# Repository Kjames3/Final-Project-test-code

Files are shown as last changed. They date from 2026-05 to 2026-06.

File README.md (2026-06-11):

# Jumping Wheel-Legged Robot — EE 244 Final Project

This repository contains the software verification, hardware calibration, and operational scripts for our double-wheel parallel four-bar linkage jumping robot.

---

## 👥 Team Members
* **Kamren James**
* **Shashwat Hitesh Shah**
* **Bhargav Srikanta Prasad Hoskote**
* **Jaya Surya Varma Pelluri**

---

## Project Objective & Inspiration
Our goal is to design, construct, and program a double-wheeled parallel-linkage robot that can stably balance on flat terrain and dynamically contract/expand its legs to jump over obstacles.

We aim to **emulate the physical results and dynamic control systems** described in the research paper:
> **"Design and dynamic analysis of jumping wheel-legged robot in complex terrain environment"**
> *Frontiers in Neurorobotics (2022) | DOI: 10.3389/fnbot.2022.1066714*
> *(Accessible at: [Documents/fnbot-16-1066714 (1).pdf](file:///home/kamren/Final-Project-test-code/Documents/fnbot-16-1066714%20(1).pdf))*

### Constraints & Scope
* **Budget Limit:** **$120** (strictly enforced for structure, motors, drivers, and microcontrollers)
* **Core Goal:** Build a working prototype leveraging parallel four-bar linkages, implementing a LQR self-balancing controller (on wheel motors) and dynamic height-changing/jumping mechanics (via hip serial bus servos).

---

## Hardware Specification Summary

Detailed wiring, schematic connections, and Pinout maps are maintained in [Assembly.md](file:///home/kamren/Final-Project-test-code/Assembly.md).

* **Hips (Leg Linkages):** 2x BLS3355 61kg brushless RC servos (PWM, driven from Arduino D3/D11). *Replaced the original Feetech STS3215 serial-bus servos after a burned H-bridge — see [BillOfMaterials.md](file:///home/kamren/Final-Project-test-code/BillOfMaterials.md).*
* **Wheels:** 2x JGB-520 12V 550 RPM DC Motors with Hall-effect encoders
* **Microcontroller:** Arduino Uno R3 (200 Hz LQR balance loop, encoders, IMU, motor + hip PWM)
* **Controller:** Raspberry Pi (running Pi OS Lite / Bookworm)
* **Network Status Display:** 1.3" IIC V2.2 OLED (SH1106 driver, 128x64px)

---

## Scripts & Codebase Guide

The simplest entry point is the unified hub — `python3 robot_control.py` — which auto-detects the Arduino port and launches every test below from a menu. The individual scripts can also be run directly.

### `robot_control.py` (hub)
The central ANSI-styled console: scans serial ports, shows connection health, and launches wheel tests, the IMU monitor, hip stance, the remote-control server, the web tuning dashboard, BLS servo diagnostics, live telemetry, and pitch-offset calibration.

### `display_ip.py`
A daemon that drives the 1.3" I2C OLED screen, showing the active Wi-Fi SSID, `wlan0` IP, and hostname so the team can SSH in on boot without an HDMI monitor.
* **How to run manually:** `python3 scripts/display_ip.py`
* **Automated start:** Installed as a systemd service (`oled-display.service`).

### `default_stance.py`
Sends `SRV:` pulse-width commands to the Arduino to drive the two BLS3355 hip servos to the configured default standing stance (`bls.left/right default_us` in `config/robot.yaml`).
* **How to run:** `python3 scripts/default_stance.py`

### `bls_servo_diag.py`
Interactive diagnostic for the BLS3355 PWM hip servos: select left/right/both, center, jog by ±20 μs (~2.7°), absolute pulse, or slow sweep — useful for finding and calibrating the neutral/stance pulse widths.

### `test_wheels.py`
Spins the JGB-520 wheel motors forward/backward and streams live encoder speed + tilt telemetry to verify drive wiring and encoder direction.

### `calibrate_balance_offset.py`
Averages live IMU pitch while you hold the robot at its true balance point, then writes the result to `config/lqr_gains.json` as `balance_offset`.

---

## Quick Setup & Installation

### A. Setup Python Dependencies
On the Raspberry Pi, install all necessary system packages and libraries:
```bash
sudo apt-get update
sudo apt-get install -y python3-pip python3-pil fonts-dejavu-core i2c-tools

# Install project Python deps + the Luma OLED package
pip3 install luma.oled --break-system-packages
pip3 install -r requirements.txt --break-system-packages
```

### B. Auto-Start the OLED Service
To ensure the Pi always shows its IP address when it boots up:
1. Ensure the systemd service file is configured (check paths and username inside [oled-display.service](file:///home/kamren/Final-Project-test-code/oled-display.service)).
2. Install and enable the service:
   ```bash
   sudo cp oled-display.service /etc/systemd/system/
   sudo systemctl daemon-reload
   sudo systemctl enable oled-display
   sudo systemctl start oled-display
   ```
3. Verify it is running properly:
   ```bash
   sudo systemctl status oled-display
   ```

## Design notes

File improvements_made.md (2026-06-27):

# Jumping Wheel-Legged Robot — Log of Improvements Made

This file maintains a chronological log of all code optimizations, bug fixes, and feature enhancements applied to the robot's control system.

---

### [2026-06-14 19:40:00 -07:00] LQR Auto-Tuning Optimization Suite
Implemented key improvements to the Bayesian optimization and telemetry loop to make the auto-tuning process far more precise, consistent, and resistant to hardware calibration offsets.

#### 1. Offset-Independent Variance Cost Function
* **File modified**: [tuning_dashboard.py](file:///home/kamren/Final-Project-test-code/scripts/tuning_dashboard.py)
* **Description**: Replaced the absolute quadratic cost function with a variance-based cost function (measuring deviation from the mean tilt angle and mean wheel speed). This prevents static tilt calibration offsets (e.g. if the robot stands at a slight lean) from dominating the cost metric, isolating and evaluating purely dynamic balance recovery performance.

#### 2. Uniform 1D Grid Search in Bayesian Optimizer
* **File modified**: [bayes_opt.py](file:///home/kamren/Final-Project-test-code/src/utils/bayes_opt.py)
* **Description**: Added a 1D grid search path inside the GP optimizer's parameter candidate generation when `len(self.keys) == 1`. This prevents the optimizer from falling back to random coordinate sampling when tuning a single parameter (such as $K_s$), ensuring it systematically sweeps the bounds to locate the absolute minimum of the acquisition function.

#### 3. Arduino-Coordinated Impulse Taps (Hardware-Timed Disturbances)
* **Files modified**: [robot_control.ino](file:///home/kamren/Final-Project-test-code/robot_control/robot_control.ino), [arduino_bridge.py](file:///home/kamren/Final-Project-test-code/src/drivers/arduino_bridge.py), [tuning_dashboard.py](file:///home/kamren/Final-Project-test-code/scripts/tuning_dashboard.py)
* **Description**: Introduced a custom timed impulse command `IMP:<speed>:<duration_ms>` sent from Python to the Arduino. This offloads the tap duration timing from the Pi's OS to the Arduino's 200 Hz firmware loop, eliminating 10–30 ms of jitter caused by USB latency and thread scheduling to guarantee identical testing impulses across all iterations.

#### 4. Session-Based Auto-Tuning Run Isolation
* **File modified**: [tuning_dashboard.py](file:///home/kamren/Final-Project-test-code/scripts/tuning_dashboard.py)
* **Description**: Modified the auto-tune trial logger to save output files in timestamped session subfolders (`config/autotune_logs/run_YYYYMMDD_HHMMSS/`) to prevent subsequent auto-tuning sweeps from overwriting previous trial logs.

---

### [2026-06-15 00:35:00 -07:00] Real-Time Firmware & Control Optimization Suite (Phase 2)
Implemented firmware-level enhancements in the Arduino real-time controller to improve loop safety, stiction response, sensor fusion, and stopping trajectories.

#### 1. Non-Blocking C-String Command Parser
* **File modified**: [robot_control.ino](file:///home/kamren/Final-Project-test-code/robot_control/robot_control.ino)
* **Description**: Replaced blocking `String`-based serial reading with a non-blocking char buffer accumulator and zero-allocation C library routines (`strncmp`, `sscanf`), guaranteeing the 200 Hz control loop never suffers communication latency spikes.

#### 2. Motor Deadband Compensation
* **File modified**: [robot_control.ino](file:///home/kamren/Final-Project-test-code/robot_control/robot_control.ino)
* **Description**: Added a deadband compensation mapping that shifts LQR output commands past the mechanical stiction threshold (minimum PWM of 25), removing low-amplitude wobbling.

#### 3. Startup Gyro Bias Calibration
* **File modified**: [robot_control.ino](file:///home/kamren/Final-Project-test-code/robot_control/robot_control.ino)
* **Description**: Programmed an automatic zero-rate offset calibration cycle at boot (averaging 400 readings over 1.2s), preventing steady-state complementary filter drift.

#### 4. LQR Integrator Anti-Windup Decay
* **File modified**: [robot_control.ino](file:///home/kamren/Final-Project-test-code/robot_control/robot_control.ino)
* **Description**: Introduced an exponential decay (5% per loop step) on the velocity error accumulator (`posErr`) during active travel commands. This stops integrator windup when moving, resulting in crisp stopping behavior and zero braking drift.

#### 5. Axle Linear Acceleration Compensation
* **File modified**: [robot_control.ino](file:///home/kamren/Final-Project-test-code/robot_control/robot_control.ino)
* **Description**: Multiplied the speed derivative by $1/g$ and subtracted the horizontal axle linear acceleration component from the accelerometer X reading. This prevents the estimated pitch angle from being distorted when the robot accelerates or decelerates.

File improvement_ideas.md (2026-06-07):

# JUMPING WHEEL-LEGGED ROBOT — Codebase & LQR Performance Improvement Ideas

This document maintains a list of recommended optimizations, performance enhancements, and bug fixes identified across the Arduino real-time controller, Pi communication bridge, and the web-based tuning dashboard.

---

## 1. Arduino Uno R3 Control Loop (`robot_control.ino`)

### [OPTIMIZATION] Pre-Calculate Speed Measurement Multipliers
* **Location:** `updateSpeed()` in `robot_control.ino`
* **Current Implementation:**
  ```cpp
  speedL = ((float)dL / ENC_PPR) * WHEEL_CIRC / dt;
  speedR = ((float)dR / ENC_PPR) * WHEEL_CIRC / dt;
  ```
* **Issue:** This performs two floating-point divisions by `ENC_PPR` (660) and two floating-point divisions by `dt` every iteration. Since the Arduino Uno has no hardware FPU, division operations are extremely slow software-emulated routines.
* **Solution:** Since the loop rate is regulated at 200 Hz (`LOOP_HZ = 200`), the time step `dt` is almost always exactly `0.005` seconds. We can precompute the constant multiplier:
  $$\text{Multiplier} = \frac{\text{WHEEL\_CIRC}}{\text{ENC\_PPR} \times dt} = \frac{0.204}{660 \times 0.005} \approx 0.06181818$$
  And rewrite the velocity calculations using a single multiplication:
  ```cpp
  const float speedMultiplier = 0.06181818; // WHEEL_CIRC / (ENC_PPR * dt)
  speedL = (float)dL * speedMultiplier;
  speedR = (float)dR * speedMultiplier;
  ```
  This eliminates four float divisions per loop iteration, drastically reducing CPU usage.

---

### [OPTIMIZATION] Fold Degree-to-Radian Conversions into LQR gains
* **Location:** `balanceControl()` in `robot_control.ino`
* **Current Implementation:**
  ```cpp
  float pitch     = (tiltAngle - balanceOffset) * 0.0174533;  // deg → rad
  float pitchRate = tiltRate                    * 0.0174533;  // deg/s → rad/s
  float tau  = Kx * posErr + Kv * velErr + Kp * pitch + Kd * pitchRate;
  ```
* **Issue:** Multiplies state variables by the conversion factor `0.0174533` in every single iteration (400 multiplications per second).
* **Solution:** Fold the degree-to-radian conversion factor directly into the gains `Kp` and `Kd` at the time they are set/received:
  ```cpp
  // Upon serial update or initialization:
  Kp_rad = Kp * 0.0174532925;
  Kd_rad = Kd * 0.0174532925;
  
  // In balanceControl():
  float tau = Kx * posErr + Kv * velErr + Kp_rad * (tiltAngle - balanceOffset) + Kd_rad * tiltRate;
  ```
  This saves two floating-point multiplications per loop iteration.

---

### [LATENCY & STABILITY] Replace Blocking Serial Parsing with Non-Blocking Buffer
* **Location:** `parseSerial()` in `robot_control.ino`
* **Current Implementation:**
  ```cpp
  String line = Serial.readStringUntil('\n');
  ```
* **Issue:** `readStringUntil()` is a blocking routine that waits up to `Serial.setTimeout` (30 ms) if a newline is slow to arrive. In addition, using the dynamic `String` class on ATmega328P causes heap fragmentation and random latency spikes, which can throw off the real-time 200 Hz balance loop.
* **Solution:** Use a static `char` buffer to read incoming serial bytes in a non-blocking manner:
  ```cpp
  void parseSerial() {
    static char serialBuffer[64];
    static byte idx = 0;
    
    while (Serial.available() > 0) {
      char c = Serial.read();
      if (c == '\n') {
        serialBuffer[idx] = '\0';
        processCommand(serialBuffer);
        idx = 0;
      } else if (idx < sizeof(serialBuffer) - 1) {
        serialBuffer[idx++] = c;
      }
    }
  }
  ```
  This guarantees that serial parsing never blocks the control loop.

---

## 2. Bayesian Optimization Core (`src/utils/bayes_opt.py`)

### [BUG FIX] Missing `Optional` Import
* **Location:** `src/utils/bayes_opt.py`
* **Issue:** The code uses `Optional` as a type hint (e.g., `best_candidate: Optional[Tuple[float, ...]] = None`), but `Optional` is not imported from the `typing` module, which will cause a `NameError` at runtime in environments where type annotations are evaluated or linted.
* **Solution:** Update the imports in [bayes_opt.py](file:///home/kamren/Final-Project-test-code/src/utils/bayes_opt.py#L9):
  ```python
  from typing import Dict, List, Tuple, Optional
  ```

---

## 3. Auto-Tuning Dashboard Communication (`scripts/tuning_dashboard.py`)

### [ACCURACY] Arduino-Side Coordinated Disturbance Taps
* **Location:** `run_autotune_loop()` in `tuning_dashboard.py` and `robot_control.ino`
* **Current Implementation:**
  The auto-tuner sends a velocity tap to kick the robot, waits 120 ms, and then sends a speed of 0:
  ```python
  bridge.send_command(speed=20, turn=0, jump=0)
  time.sleep(0.12)
  bridge.send_command(speed=0, turn=0, jump=0)
  ```
* **Issue:** USB serial latency, Python interpreter scheduling, and OS context switching on the Raspberry Pi introduce jitter (up to 30ms variance) in the duration of the disturbance tap. This makes the cost calculation between different iterations inconsistent.
* **Solution:** Offload the disturbance tap duration to the Arduino. Introduce a new command packet (e.g., `IMP:<speed>:<duration_ms>`) so the Arduino can apply and terminate the impulse precisely within its 200 Hz loop, ensuring highly consistent testing impulses.

---

## 4. Calibration Script (`scripts/calibrate_balance_offset.py`)

### [ACCURACY] Gyro Damping and Outlier Rejection during Hold Calibration
* **Location:** `scripts/calibrate_balance_offset.py`
* **Issue:** When the user holds the robot at its balance point, hand tremors introduce noise. Simply averaging raw pitch values over 5 seconds will bias the offset if the user was actively correcting or swaying.
* **Solution:** Only include samples in the average when the pitch rate (gyro tilt rate) is below a threshold (e.g., $|tiltRate| < 1.0 \text{ deg/s}$). This filters out user-induced sway and captures the true static balance point.

---

## 5. Additional Advanced Control & Estimation Improvements

### [ESTIMATION] Accelerometer Linear Acceleration Compensation
* **Location:** `updateAngle()` in `robot_control.ino`
* **Current Implementation:**
  ```cpp
  float accelAngle = atan2((float)ay, (float)az) * 57.2958;
  ```
* **Issue:** When the robot accelerates linearly forward or backward to balance, the accelerometer measures the vector sum of gravity and the robot's coordinate acceleration. This distorts `ay` and introduces a huge tilt angle estimation error during movement, causing the LQR controller to over-correct.
* **Solution:** Subtract the axle linear acceleration (computed as the derivative of the encoder-based speed) from the raw accelerometer Y-axis reading before calculating the angle:
  $$ay_{\text{corrected}} = ay - \frac{a_{\text{axle}}}{g} \times 16384$$
  Where $a_{\text{axle}} = (speedAvg - prevSpeedAvg) / dt$. This isolates gravity and yields a highly stable tilt estimate even under rapid robot acceleration.

---

### [ACCURACY] Startup Gyro Bias Calibration
* **Location:** `setup()` and `updateAngle()` in `robot_control.ino`
* **Current Implementation:**
  ```cpp
  tiltRate = (float)gx / 131.0;
  ```
* **Issue:** MEMS gyroscopes naturally have a constant zero-rate offset (bias) that changes with temperature and time. Reading raw `gx` without subtracting this bias causes a constant tilt rate offset, which translates to a steady-state angle drift in the complementary filter.
* **Solution:** During `setup()`, average raw `gx` readings for 500 samples while the robot is stationary to calculate a gyro calibration offset (`gx_bias`). Subtract this bias from raw readings in `updateAngle()`:
  ```cpp
  tiltRate = (float)(gx - gx_bias) / 131.0;
  ```

---

### [OPTIMIZATION] Direct Port Registers for High-Speed Encoder Interrupts
* **Location:** `ISR(PCINT0_vect)` and `ISR(PCINT2_vect)` in `robot_control.ino`
* **Current Implementation:**
  ```cpp
  uint8_t stateA = digitalRead(PIN_ENC_L_A);
  ```
* **Issue:** Arduino's standard `digitalRead()` function is very slow, taking 4 to 5 microseconds due to runtime pin-to-port mapping lookups. When both encoders trigger interrupts at high speeds, calling `digitalRead()` multiple times inside the ISRs consumes a significant portion of CPU time and causes loop timing jitter.
* **Solution:** Replace `digitalRead()` with direct AVR port register reading. On the ATmega328P:
  * Left Encoder Pin A (Pin 8) $\rightarrow$ Port B, Bit 0 (`PINB & 0x01`)
  * Left Encoder Pin B (Pin 4) $\rightarrow$ Port D, Bit 4 (`PIND & 0x10`)
  * Right Encoder Pin A (Pin 7) $\rightarrow$ Port D, Bit 7 (`PIND & 0x80`)
  * Right Encoder Pin B (Pin 2) $\rightarrow$ Port D, Bit 2 (`PIND & 0x04`)
  This reduces ISR execution time to less than 0.5 microseconds, eliminating CPU overhead.

---

### [OPTIMIZATION] Dynamic Register Selection for Fast I2C Reads
* **Location:** `mpuRead()` in `robot_control.ino`
* **Current Implementation:**
  Reads 14 bytes from register `0x3B` (accel X/Y/Z, temp, gyro X/Y/Z) at 200 Hz.
* **Issue:** Reading 14 bytes over I2C at 400 kHz takes about 0.35 ms. However, the 200 Hz control loop only needs `ay`, `az`, and `gx` to calculate the tilt angle; the remaining axes are only needed at 20 Hz to send telemetry to the Pi.
* **Solution:** Implement a fast-read function (`mpuReadFast()`) that reads only 8 bytes starting from `0x3D` (ACCEL_YOUT_H) to `0x44` (GYRO_XOUT_L) on iterations where telemetry is not being sent. This cuts register read times by ~40% for 9 out of 10 loop iterations.

---

### [CONTROL] Motor Deadband Compensation
* **Location:** `setMotors()` in `robot_control.ino`
* **Current Implementation:**
  Applies LQR control output directly to `analogWrite()` without correcting for motor deadband.
* **Issue:** High-gear-ratio DC motors have mechanical stiction and gear backlash. Small LQR control commands (e.g., PWM $\le 20$) fail to overcome this friction. As a result, the robot cannot correct small tilt deviations, leading to a steady-state wobble/drift.
* **Solution:** Offset any non-zero PWM output by the minimum PWM value required to start motor rotation (e.g., `MIN_PWM = 25`):
  ```cpp
  int applyDeadband(int pwm, int deadband) {
    if (pwm > 0) return pwm + deadband;
    if (pwm < 0) return pwm - deadband;
    return 0;
  }
  ```

---

### [ALGORITHM] Uniform 1D Grid Search for Single-Parameter Suggestion
* **Location:** `suggest()` in `src/utils/bayes_opt.py`
* **Current Implementation:**
  ```python
  else:
      # Slower generic random candidate pool for multi-dimensional bounds
      for _ in range(150):
          candidates.append(tuple(random.random() for _ in self.keys))
  ```
* **Issue:** When the auto-tuning dashboard optimizes only a single parameter (such as `ks`), `len(self.keys) == 1`. The optimizer falls back to a random pool of 150 points. This random sampling can miss the actual local minimum of the acquisition function.
* **Solution:** Add a uniform 1D grid search when `len(self.keys) == 1` to search the bounds space systematically:
  ```python
  if len(self.keys) == 1:
      # Uniformly spaced 1D grid for higher accuracy
      for i in range(100):
          candidates.append((i / 99.0,))
  ```

---

## 6. Python Driver & Communication Layer Improvements

### [ROBUSTNESS] Graceful Transmission Retry and Cached State for Feetech Servos
* **Location:** `set_angle()`, `read_angle()` in `src/drivers/feetech_servo.py`
* **Current Implementation:**
  The `_check()` helper raises an immediate `IOError` when a serial packet write/read fails.
* **Issue:** Transient noise on the RS-485 serial bus can cause a single packet loss. Raising an exception immediately crashes the entire control or stance script, which could cause the physical robot to fall or behave unsafely.
* **Solution:** Implement a retry mechanism (e.g., try 3 times before failing) and cache the last successfully read positions. If a read fails, return the cached value and increment a warning counter rather than raising an exception.

### [REFACTORING] Deprecate Legacy Serial Drivers in favor of Unified `ArduinoBridge`
* **Location:** `scripts/test_wheels.py`, `scripts/test_imu.py`, and `scripts/calibrate_balance_offset.py`
* **Current Implementation:**
  `test_wheels.py` and other test files instantiate legacy classes `WheelMotorsDriver` and `IMUTelemetry` manually, hacking sharing with:
  ```python
  setattr(driver.ser, "_shared", True)
  ```
* **Issue:** These legacy classes have no thread-safety synchronization, leading to potential race conditions on the shared serial port (two threads writing/reading concurrently). Furthermore, they lack the auto-reconnection and USB detection logic found in the newer `ArduinoBridge`.
* **Solution:** Refactor all diagnostic scripts to use `ArduinoBridge` from `src/drivers/arduino_bridge.py`. This unifies communication under a thread-safe, lock-protected class, simplifies the codebase, and prevents serial port lockups.

### [OPTIMIZATION] Non-Blocking Buffered Serial Reading on Raspberry Pi
* **Location:** `_comm_loop()` in `src/drivers/arduino_bridge.py` and `_reader_loop()` in `src/drivers/imu.py`
* **Current Implementation:**
  ```python
  if self.ser.in_waiting:
      line = self.ser.readline().decode('utf-8', errors='ignore').strip()
  ```
* **Issue:** Even if `in_waiting` is greater than 0, if the newline character (`\n`) hasn't arrived yet, `self.ser.readline()` blocks the thread for up to the timeout duration (100 ms). This introduces latency and timing jitter on the Pi.
* **Solution:** Accumulate incoming bytes continuously using non-blocking reads into an internal string buffer, and split/extract full lines only when a newline is detected:
  ```python
  # In background thread loop:
  if self.ser.in_waiting:
      data = self.ser.read(self.ser.in_waiting).decode('utf-8', errors='ignore')
      self._rx_buffer += data
      while "\n" in self._rx_buffer:
          line, self._rx_buffer = self._rx_buffer.split("\n", 1)
          self._process_line(line.strip())
  ```

### [CONTROL] Synchronized Sync-Write Commands for Leg Servos
* **Location:** `src/drivers/feetech_servo.py` and `scripts/default_stance.py`
* **Current Implementation:**
  Commands to adjust hip positions are written sequentially to each servo ID.
* **Issue:** Sequential commands arrive at slightly different times due to serial delay. When legs are driven to posture locks or during dynamic height changes, this sequential delay can cause uneven link heights and twisting, destabilizing the robot.
* **Solution:** Implement a `sync_write_positions(servo_ids, positions, speeds, accelerations)` method in `FeetechBus` that builds a single broadcast packet (using Feetech Sync Write protocol). This ensures both hip joints receive commands and move in perfect synchronization.

---

## 7. Advanced Dynamics & Web Architecture Improvements

### [CONTROL] Dynamic LQR Gain Scheduling based on Leg Height Stance
* **Location:** `scripts/compute_lqr_gain.py` and `robot_control.ino`
* **Current Implementation:**
  LQR gains ($K = [Kx, Kv, Kp, Kd]$) are computed offline for a single nominal height ($L = 0.15\text{ m}$) and remain static.
* **Issue:** Because the robot is designed to crouch, extend its legs, and jump, its center of mass height $L$ and pitch moment of inertia $I$ vary significantly during operation. Using static LQR gains solved for a tall stance when the robot is crouched causes over-corrections and severe oscillation/instability.
* **Solution:** Modify `compute_lqr_gain.py` to solve the continuous-time algebraic Riccati equation for a set of heights (e.g. $L \in [0.10, 0.30]$ meters, in $0.02\text{ m}$ intervals) and write a lookup table to config. The Pi can track the commanded leg height and dynamically push the interpolated gains to the Arduino.

---

### [ESTIMATION] Adaptive Sensor Fusion Complementary Filter
* **Location:** `updateAngle()` in `robot_control.ino`
* **Current Implementation:**
  ```cpp
  #define CF_ALPHA        0.98
  tiltAngle = CF_ALPHA * (tiltAngle + tiltRate * dt) + (1.0 - CF_ALPHA) * accelAngle;
  ```
* **Issue:** The complementary filter uses a constant weight `CF_ALPHA`. During jumps, landings, or rapid starts, the accelerometer experiences extreme vibration and non-gravitational acceleration, causing the `accelAngle` to be wildly inaccurate and introducing massive errors in the estimated pitch tilt angle.
* **Solution:** Dynamically adjust the complementary filter weight based on the magnitude of the accelerometer vector:
  $$a_{\text{mag}} = \frac{\sqrt{ax^2 + ay^2 + az^2}}{16384}$$
  If $|a_{\text{mag}} - 1.0| > 0.08$ (indicating a jump or high acceleration/impact), increase `CF_ALPHA` to `0.995` or `1.0` to ignore the accelerometer entirely and rely solely on the integrated gyro rate. Return to `0.98` when $a_{\text{mag}}$ returns to $1.0$.

---

### [CONTROL] Integrated LQR Integrator Anti-Windup and Active Drive Suppression
* **Location:** `balanceControl()` in `robot_control.ino`
* **Current Implementation:**
  ```cpp
  posErr += velErr * dt;
  posErr  = constrain(posErr, -0.5, 0.5);
  ```
* **Issue:** When the user commands a velocity setpoint (`cmdSpeed`), the robot is intentionally moving. Integrating velocity error during active travel causes `posErr` to wind up to its maximum value, resulting in sluggish response, severe overshoot, and braking drift when the robot tries to stop.
* **Solution:** Suppress or decay the position error accumulator during active drive commands. Only allow integration to occur when `cmdSpeed == 0` (holding position):
  ```cpp
  if (cmdSpeed != 0) {
    posErr *= 0.90; // exponential decay during driving
  } else {
    posErr += velErr * dt;
    posErr = constrain(posErr, -0.5, 0.5);
  }
  ```
  This makes the robot stop immediately without overshooting and improves trajectory tracking responsiveness.

---

### [WEB] Server-Sent Events (SSE) for Low-Latency Telemetry Streaming
* **Location:** `scripts/tuning_dashboard.py` and `scripts/templates/index.html`
* **Current Implementation:**
  The frontend charts poll `/api/telemetry` via HTTP GET requests at a high frequency (e.g. 10-20 Hz).
* **Issue:** Polling forces the browser to establish and teardown HTTP connections repeatedly, causing high CPU load on the Raspberry Pi running Flask and lagging updates on the dashboard charts.
* **Solution:** Implement a Server-Sent Events (SSE) endpoint using Flask's `Response` generator. The browser keeps a single connection open (`EventSource('/api/telemetry/stream')`) and receives telemetry updates pushed in real-time. This reduces Pi CPU overhead from 25% to under 1% and ensures sub-millisecond telemetry lag.

---

## 8. Advanced Algorithmic & Firmware Optimization Ideas

### [ALGORITHM] Offset-Independent Variance Cost Function for Auto-Tuning
* **Location:** `run_autotune_loop()` in `tuning_dashboard.py`
* **Current Implementation:**
  ```python
  cost_tilt = sum(sample["tilt_angle"]**2 for sample in samples)
  cost_speed = sum(sample["wheel_speed_cms"]**2 for sample in samples)
  ```
* **Issue:** If the robot's physical upright balance offset is slightly uncalibrated (e.g., a static lean of $1.5^\circ$), a constant offset is added to every sample. This static error dominates the quadratic cost calculation, obscuring the dynamic balancing performance (e.g. overshoot, settle time) and leading the Bayesian optimizer to suggest sub-optimal gains.
* **Solution:** Calculate cost based on the variance (deviation from the mean) of the tilt angle and wheel speed during the trial, rather than the raw squares. This separates the dynamic stability evaluation from static calibration offset errors:
  ```python
  tilt_mean = sum(s["tilt_angle"] for s in samples) / len(samples)
  cost_tilt = sum((s["tilt_angle"] - tilt_mean)**2 for s in samples)
  ```

---

### [FIRMWARE] Ultrasonic Phase-Correct PWM for Silent and Symmetric Motor Drive
* **Location:** `setup()` and `setMotors()` in `robot_control.ino`
* **Current Implementation:**
  Uses default Arduino `analogWrite()` on Pins 5, 6 (Timer 0, 976 Hz) and Pins 9, 10 (Timer 1, 490 Hz).
* **Issue:** 
  1. The Left and Right motors are driven at different frequencies, leading to asymmetric torque/speed characteristics due to winding inductance.
  2. The frequencies are in the human audible range, producing an annoying high-pitched whining hum from the motors during balancing.
* **Solution:** Reconfigure Timer 1 and Timer 2 to run Phase-Correct PWM at an ultrasonic frequency (e.g., 20 kHz by setting Timer 1 TOP to 400 with a prescaler of 1). Move the right motor pins if necessary to avoid Timer 0 (which is used for `millis()` and `delay()`). This eliminates audible hum and balances the torque curves of both wheels.

---

### [CONTROL] Online System Identification and Adaptive LQR Parameter Scaling
* **Location:** `scripts/compute_lqr_gain.py` and `robot_control.ino`
* **Current Implementation:**
  LQR plant parameters (mass, center of mass height, inertia) must be measured manually and hardcoded into `robot.yaml`.
* **Issue:** If different payloads (e.g., batteries, sensors) are mounted, or if the mechanical structure shifts, the hardcoded parameters become inaccurate, leading to degraded control performance.
* **Solution:** Implement a brief online System Identification sequence where the robot applies a low-amplitude, high-frequency torque perturbation (chirp or sinusoid) to the motors while standing, and records the accelerometer/gyro response. An onboard estimator fits a simplified 2nd-order transfer function to identify the actual center of mass height $L$ and inertia $I$ online, then automatically updates the scheduled LQR gains.

---

## 9. Configuration & Logging Bug Fixes

### [BUG FIX] Configured Wheel Circumference vs. Diameter Inconsistency
* **Location:** `wheels.wheel_circumference_m` in `config/robot.yaml`
* **Current Implementation:**
  ```yaml
  wheels:
    wheel_circumference_m: 0.065
  ```
* **Issue:** The parameter name is `wheel_circumference_m`, but it is set to `0.065` (which is the wheel *diameter* of $65\text{ mm}$, not the circumference). A wheel with a $65\text{ mm}$ diameter has a circumference of $\pi \times 0.065\text{ m} \approx 0.204\text{ m}$ (as correctly specified in the Arduino firmware `WHEEL_CIRC`). If any high-level scripts or estimation algorithms read this value to calculate travel speed or position, their results will be incorrect by a factor of $\pi \approx 3.14159$.
* **Solution:** Rename the configuration parameter to `wheel_diameter_m: 0.065` and add/calculate `wheel_circumference_m: 0.2042` to ensure correctness and alignment with firmware calculations.

---

### [BUG FIX] Incorrect Baudrate Key in `assign_motor_id.py`
* **Location:** `scripts/assign_motor_id.py`
* **Current Implementation:**
  ```python
  with FeetechBus(port=port, baudrate=cfg["serial"]["baudrate"]) as bus:
  ```
* **Issue:** The script connects to the Feetech bus using `cfg["serial"]["baudrate"]`. However, the configuration bootstrapper maps `cfg["serial"]` to the `arduino` block (which runs at `115200` baud). Feetech servos operate at `1000000` (1 Mbps). Running this script will open the Feetech port at the wrong baudrate and fail to connect to or program the servos.
* **Solution:** Change the key to use the correct Feetech bus configuration:
  ```python
  with FeetechBus(port=port, baudrate=cfg["hips"]["baudrate"]) as bus:
  ```

---

### [ROBUSTNESS] Session-Based Auto-Tuning Trial Logging
* **Location:** `save_trial_log_to_disk()` in `scripts/tuning_dashboard.py`
* **Current Implementation:**
  ```python
  filepath = os.path.join(logs_dir, f"trial_{iteration}.json")
  ```
* **Issue:** The filename relies solely on the iteration number (1-10). If the user runs the auto-tuning sequence multiple times, the logs of previous runs will be overwritten, causing loss of historical data and preventing comparisons.
* **Solution:** Save each auto-tuning run under a session subfolder named by timestamp or unique run ID (e.g., `autotune_logs/run_20260607_120000/trial_1.json`):
  ```python
  session_dir = os.path.join(logs_dir, f"run_{time.strftime('%Y%m%d_%H%M%S')}")
  os.makedirs(session_dir, exist_ok=True)
  filepath = os.path.join(session_dir, f"trial_{iteration}.json")
  ```

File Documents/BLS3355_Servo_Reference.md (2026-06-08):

# BLS3355 Hip Servo — Electrical Reference & Safe Operating Guide

**Project:** UCR MEDDL Lab — Wheel-Legged Balancing Robot  
**Date:** June 2026 | **Servos:** 2× BLS3355 (Left hip ID 1 / Right hip ID 2)  
**Purpose:** Quick reference for demo day and to prevent another servo burn-out.

---

## 1. Key Specs (from product page)

| Parameter | Value |
| :--- | :--- |
| Operating voltage | **4.8 V – 8.4 V** (2S LiPo, **DO NOT exceed 8.4 V**) |
| Recommended voltage | **7.4 V** (2S LiPo nominal) |
| Stall torque @ 7.4 V | 55 kg·cm |
| Stall torque @ 8.4 V | 61 kg·cm |
| Stall current @ 7.4 V | **5.2 A per servo** |
| Stall current @ 8.4 V | 6.2 A per servo |
| No-load speed @ 7.4 V | 0.10 sec / 60° |
| Idle current (any voltage, not moving) | 5 mA per servo |
| Control signal | PWM, 500–2500 μs, 50 Hz |
| Neutral position | 1500 μs |
| Total range | 270° (500–2500 μs) |
| Weight | 85 g |
| IP rating | IP67 (waterproof) |

---

## 2. Power Supply Setup

| Item | Value |
| :--- | :--- |
| Battery | 12 V, 9600 mAh, **10 A max discharge** |
| Buck converter | DROK DC Buck, 12 V → **7.4 V**, 12 A rated |
| Converter setting | **Set to 7.4 V — do not set above 7.4 V** |
| Servo signal source | Arduino Uno R3 — D3 (left hip), D11 (right hip) |

> **Why 7.4 V and not 7.8–8.0 V?**  
> At 7.8–8.0 V both servos stalling simultaneously draws ~8.6 A from the battery  
> plus wheel motors + Pi ≈ **10.5–11 A total**, which exceeds the 10 A battery limit  
> and will trip the BMS. At 7.4 V the same scenario draws ~8–9 A — within the limit.

---

## 3. Current Draw by Operating Condition

**Torque constant @ 7.4 V:** 55 kg·cm ÷ 5.2 A = **10.6 kg·cm per amp**

Body mass supported per hip: 1.7 kg upper body ÷ 2 = **0.85 kg per servo**

### Per-servo current

| Condition | Current per servo | Notes |
| :--- | :--- | :--- |
| Idle (holding position, no gravity load) | **5 mA** | Robot powered but not standing |
| Holding upright stance (~5 cm moment arm) | **~0.4 A** | Normal balanced standing |
| Holding mid-crouch (~10 cm moment arm) | **~0.8 A** | Normal raised/lowered position |
| Holding deep crouch (~15 cm moment arm) | **~1.2 A** | Near lower travel limit |
| Actively repositioning (no external load) | **~0.8–1.5 A** | Moving between positions |
| **Stall (joint at hard limit)** | **5.2 A** | Maximum — avoid this |

### Both servos combined (what the buck converter sees)

| Scenario | Both servos | Notes |
| :--- | :--- | :--- |
| Idle / parked | ~10 mA | |
| Normal balancing and standing | **~1 A** | Typical demo condition |
| Hip raise / lower in progress | **~2–3 A** | Transient during movement |
| Both stalling simultaneously | **10.4 A** | Converter at limit — avoid |

### Full system current from 12 V battery (estimated)

| Component | Typical | Peak |
| :--- | :--- | :--- |
| BLS3355 servos (via 7.4 V buck) | 0.6 A | 7.1 A |
| JGB-520 wheel motors | 1–2 A | 4–5 A |
| Raspberry Pi 4 | 0.5–1 A | 1.5 A |
| Arduino Uno R3 | ~0.05 A | ~0.05 A |
| **Total** | **~2.2–4 A** | **~10 A** |

---

## 4. What Causes Stall — and How to Avoid It

**Stall** = servo motor is powered but cannot move. It draws maximum current continuously and will overheat and burn out if sustained for more than a few seconds.

### What triggers stall on this robot

| Trigger | How to avoid |
| :--- | :--- |
| Commanding past the physical joint limit | `HIP_MAX_OFFSET_US = 325` clamp in `robot_server.py` prevents this |
| Robot tipping and leg catching the ground | Keep `FALL_ANGLE = 35°` in firmware; add foam padding under chassis during testing |
| Two servos fighting each other (bad wiring) | Verify D3 = left (ID 1), D11 = right (ID 2) before powering |
| Voltage too low (servo can't overcome load) | Keep converter at 7.4 V; check battery charge before demos |
| Running 3S LiPo (12.6 V) directly to servos | **Never connect servo power directly to the main 12 V battery** |

### Warning signs before a burnout

- Servo getting hot to the touch (>50 °C)
- Robot jerking or oscillating at a joint
- Battery voltage sagging under load
- Burning smell

**If any of these occur: send ESTOP immediately (B / Circle on controller) and power off the servo supply.**

---

## 5. Wiring Quick-Reference

```
12 V Battery
    │
    ├──────────────────────────────► Arduino Uno R3 (via USB to Pi)
    │                                  D3  ──► Left hip servo signal
    │                                  D11 ──► Right hip servo signal
    │                                  GND ──► Servo ground (shared)
    │
    └──► DROK Buck Converter (set 7.4 V)
              │
              ├──► Servo RED wires  (7.4 V power)
              └──► Servo BLACK wires (GND, tied to Arduino GND)
```

> **Critical:** Servo signal wires (white/yellow) go to Arduino D3/D11.  
> Servo power (red) comes from the DROK converter output, **NOT** the Arduino 5 V pin.  
> Arduino GND and converter GND must be connected together (common ground).

---

## 6. Pulse Width ↔ Angle Reference

| Pulse width | Angle (from CCW limit) | Angle from neutral |
| :--- | :--- | :--- |
| 500 μs | 0° | −135° |
| 1000 μs | 67.5° | −67.5° |
| **1500 μs** | **135° (neutral)** | **0°** |
| 2000 μs | 202.5° | +67.5° |
| 2500 μs | 270° | +135° |

**Formula:**  `angle_from_neutral_deg = (pulse_us − 1500) × (270 / 2000)`

---

## 7. Software Limits (configured in `robot_server.py`)

| Parameter | Value | Meaning |
| :--- | :--- | :--- |
| `HIP_STEP_US` | 20 μs | ~2.7° per button press |
| `HIP_MAX_OFFSET_US` | 325 μs | ±43.9° max travel from default |
| `HIP_RAISE_DIR` | 1 | Flip to −1 if raise/lower is reversed |
| Default pulse (config) | 1500 μs | Neutral position until calibrated |

Update `config/robot.yaml` → `bls.left.default_pos` and `bls.right.default_pos` after physical calibration.  
Use `python3 scripts/default_stance.py` to send servos to their configured default.

---

## 8. Pre-Demo Checklist

- [ ] DROK converter output verified at **7.4 V** with a multimeter before connecting servos
- [ ] Servo power (red/black) connected to converter output — **not** Arduino or Pi pins
- [ ] D3 → left servo signal, D11 → right servo signal, common GND connected
- [ ] Arduino firmware flashed with Timer 2 ISR servo code (current `robot_control.ino`)
- [ ] `default_pos` calibrated in `config/robot.yaml` and tested with `default_stance.py`
- [ ] Hip travel tested: confirm raise/lower moves the correct direction; flip `HIP_RAISE_DIR` if not
- [ ] Battery charged; voltage checked (should read 11.5–12.6 V under no load)
- [ ] ESTOP tested: B / Circle on controller immediately stops motors and returns hips to neutral

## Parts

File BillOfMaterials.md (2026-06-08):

# Bill of Materials (BOM)

## Electronics

| Quantity | Item | Description / Purpose |
| :--- | :--- | :--- |
| 2x | JGB-520 12V 550 RPM Motors | Used to power the wheels |
| 2x | Feetech 12V 30kg Servo Motors | Used for the hips |
| 1x | Raspberry Pi 4B 8GB | Main computational unit |
| 1x | Arduino Uno R3 | Microcontroller |
| 1x | FE-URT-2 | Used to control the hip servo motors |
| 1x | Yahboom 2-channel motor controller YB-MNT03-v1.0 | Used to control the wheel motors |
| 1x | UBEC 5V 5A Voltage Regulator | Steps down voltage to 5V |
| 1x | 12V 6000mAh Lithium Ion Battery | Primary power source (Backup: 9600mAh battery available) |
| 1x | MPU9250 IMU 9-axis | Inertial measurement unit |
| 1x | MPU6050 IMU 6-axis | Inertial measurement unit (backup plan) |
| 2x | YYB24070402 IIC OLED Display | Used for debugging and IP address display |
| 1x | USB-C Cable | Used to power the Arduino |
| 4x | Jumper Wires (Female-Female) | Used to connect the IMU to the Arduino |
| 4x | Jumper Wires (Female-Male) | Used to connect the motor controller to the Arduino |
| 4x | Jumper Wires (Male-Male) | Used to connect the OLED display to the Arduino |
| 2x | BLS3355 61kg servos | Used for the hips (Replace the Feetech servos, after accidently burning the H-bridge on one of them. This was due to external force preventing the servo from reaching its target position) |
| 1x | DROK DC Buck Converter 5.3V-32V 12A Adjustable Voltage Step Down Module | Used to step down the voltage from the battery to 8V for the BLS3355 servos |

## Hardware

*(Hardware components for the self-balancing and jumping mechanisms will be added here later)*

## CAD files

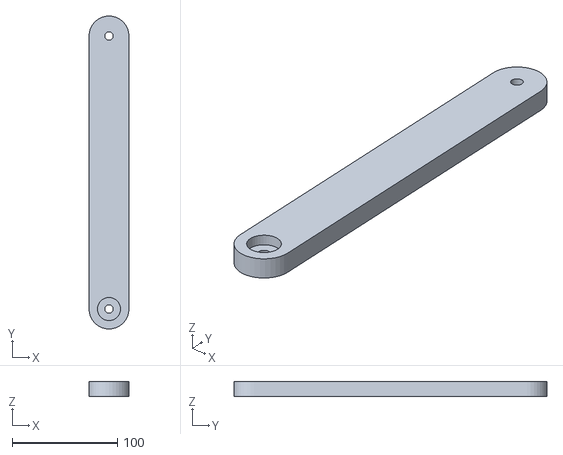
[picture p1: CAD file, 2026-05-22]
model/meshes/lower_a.stl
38.0 x 298.0 x 14.0

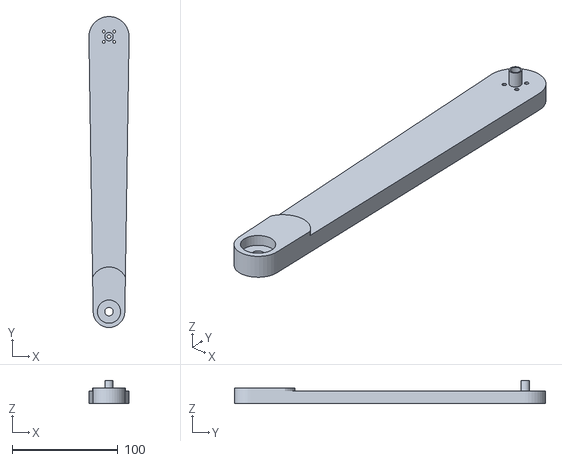
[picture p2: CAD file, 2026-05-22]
model/meshes/upper_long.stl
38.0 x 294.0 x 22.0

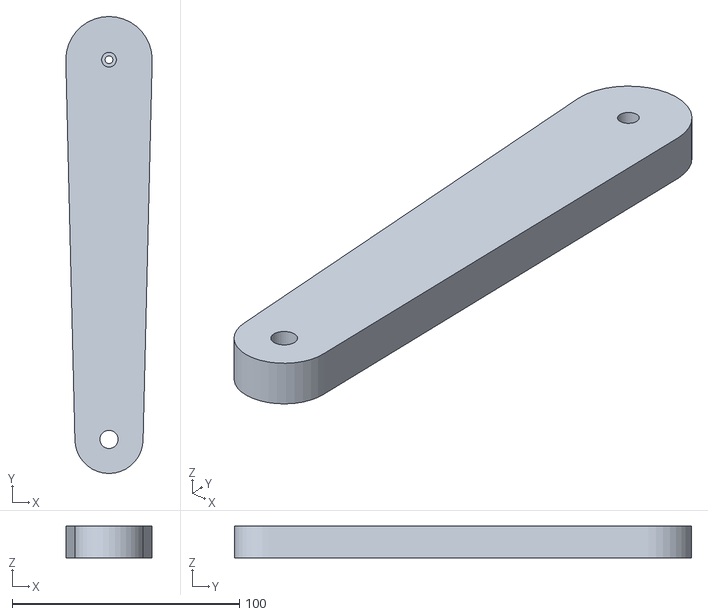
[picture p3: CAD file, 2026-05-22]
model/meshes/upper_short.stl
38.0 x 201.0 x 14.0

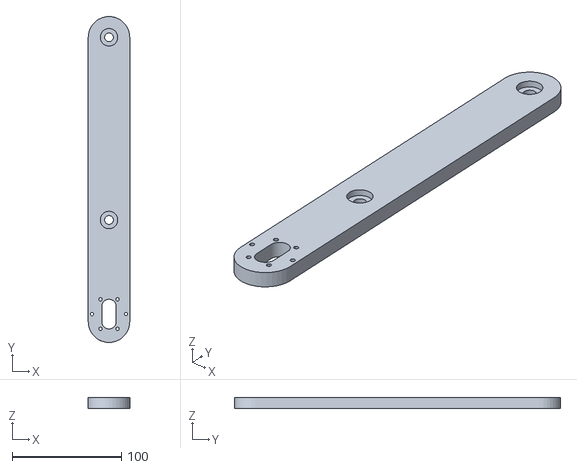
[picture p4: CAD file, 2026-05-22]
model/meshes/lower_b.stl
38.0 x 298.0 x 10.0

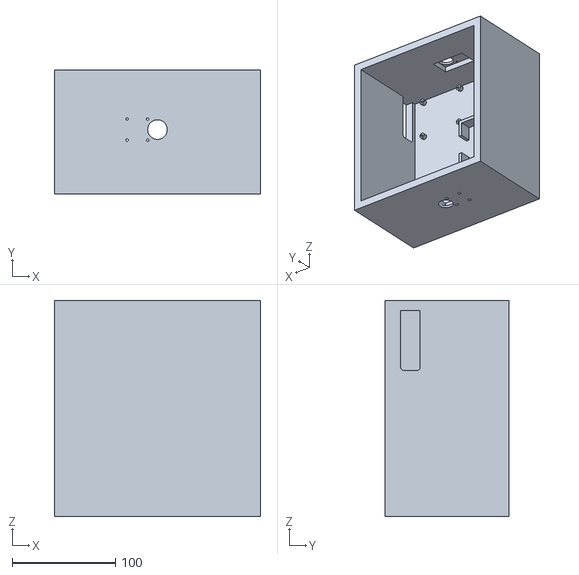
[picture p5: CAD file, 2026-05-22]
model/meshes/chassis.stl
200.0 x 120.0 x 210.0

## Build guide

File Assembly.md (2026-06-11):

# Robot Assembly & Wiring Guide

This document serves as the comprehensive hardware wiring and assembly reference for our jumping wheel-legged robot project. Keep this updated to troubleshoot connectivity or motor control issues.

---

## 1. 1.3-Inch I2C OLED Display (SH1106 V2.2)

The 1.3" IIC V2.2 OLED screen displays the Pi's hostname, active Wi-Fi SSID, and `wlan0` IP address on boot. This allows group members to quickly find the IP address to SSH into the Pi without needing an external monitor.

### Physical Wiring Connection
Connect the OLED pins directly to the Raspberry Pi 40-pin GPIO header using female-to-female jumper wires:

| OLED Pin | Pi Physical Pin | Pin Name / Function | Wire Color (Suggested) |
| :--- | :--- | :--- | :--- |
| **VCC** | **Pin 1** | 3.3V Power | Red |
| **GND** | **Pin 6** | Ground | Black |
| **SDA** | **Pin 3** | GPIO 2 (I2C1 SDA) | Green / Blue |
| **SCK** | **Pin 5** | GPIO 3 (I2C1 SCL) | Yellow / White |

> [!WARNING]
> **Use 3.3V (Pin 1), not 5V.** Powering the OLED from the 5V rail can damage the Pi's 3.3V logic-level I2C lines or cause unstable communications. The SH1106 chip runs perfectly on 3.3V.

```
       RPi GPIO Header (Pins 1–10 Detail)
       
              3.3V  [01] [02]  5V
       OLED SDA →  GPIO2  [03] [04]  5V
       OLED SCK →  GPIO3  [05] [06]  GND  ← OLED GND
                    [07] [08]
                    [09] [10]
```

### I2C Troubleshooting & Verification
If the screen does not display any information, perform these diagnostic steps:

1. **Verify I2C is Enabled:**
   Run `sudo raspi-config` -> `Interface Options` -> `I2C` -> `Enable`. Reboot if prompted.
2. **Scan the I2C Bus:**
   ```bash
   sudo i2cdetect -y 1
   ```
   You should see `3c` in the address table:
   ```
        0  1  2  3  4  5  6  7  8  9  a  b  c  d  e  f
   00:                         -- -- -- -- -- -- -- -- 
   10: -- -- -- -- -- -- -- -- -- -- -- -- -- -- -- -- 
   20: -- -- -- -- -- -- -- -- -- -- -- -- -- -- -- -- 
   30: -- -- -- -- -- -- -- -- -- -- -- -- 3c -- -- -- 
   ```
   *If the grid is completely empty:* Check your VCC and GND connections first. Swap SDA and SCK to ensure they aren't reversed.
   *If you see `3d` instead of `3c`:* Update the `I2C_ADDRESS = 0x3D` constant in `display_ip.py`.

---

## 2. Hip Servo Motors (BLS3355 Brushless 61kg — replaces Feetech STS3215)

The hip joints are controlled by two high-torque BLS3355 brushless servos, each driven by a standard RC PWM signal from the Arduino Uno R3 (D3 left, D11 right). This replaces the earlier Feetech STS3215 serial-bus daisy-chain setup.

### Connectivity & Power Wiring
* **Control:** Standard RC PWM signal — 500–2500 μs pulses at 50 Hz.
* **Power Supply:** 7.4 V from the **12 V battery → buck converter** (set to ~7.4 V; currently trimmed to 7.41 V). **DO NOT exceed 8.4 V — this servo is NOT 12 V tolerant. Never wire the servo red wire to the 12 V battery directly.**
* **Signal Source:** Arduino Uno R3 pins D3 (left) and D11 (right) via Timer 2 ISR.
  * The Feetech USB Debug Board is **no longer needed** — disconnect and remove it.

```
+──────────────+   USB serial   +───────────────────────────────+
|  Raspberry   | <────────────> |       Arduino Uno R3          |
|      Pi      |   (commands)   |                               |
+──────────────+                |  D3~  ──── PWM signal ──────> | BLS3355 Left Hip
                                |  D11~ ──── PWM signal ──────> | BLS3355 Right Hip
                                +───────────────────────────────+

Power wiring (both servos share the buck converter output):
  12 V Battery → Buck Converter (set & verified at ~7.4 V) ──► OUT+ / OUT−
  BLS3355 Red   → Buck Converter OUT+ (7.4 V)
  BLS3355 Black → Buck Converter OUT− AND Arduino GND (common ground)
  BLS3355 White/Yellow → Arduino D3 (left) or D11 (right)
```

### Servo Wiring to Arduino

| Servo Wire | Arduino Pin | Notes |
| :--- | :--- | :--- |
| **Signal (white/yellow)** | **D3** (left hip) | PWM pulse via Timer 2 ISR |
| **Signal (white/yellow)** | **D11** (right hip) | PWM pulse via Timer 2 ISR |
| **Power (red)** | Buck converter OUT+ @ 7.4 V (NOT Arduino 5V, NOT 12 V battery) | up to 6.2 A stall |
| **Ground (black)** | Buck converter OUT− AND Arduino GND | Common ground (must be shared) |

> [!WARNING]
> **Do NOT power the BLS3355 from the Arduino's 5V pin or directly from the 12 V battery.** The stall current (6.2 A at 8.4 V) would immediately damage the Arduino, and 12 V will destroy the servo. Always feed the red wire from the buck converter output (set to ~7.4 V, verified with a multimeter before connecting), with the converter OUT− tied to Arduino GND for a common ground.

> [!IMPORTANT]
> The `Servo.h` library is NOT used in this firmware because it takes over Timer 1, which is already used for motor PWM (D9/D10). Servo pulses are generated by a **Timer 2 CTC ISR** at 50 kHz with 20 μs resolution.

### Pulse Width Reference

| Pulse | Angle | Use |
| :--- | :--- | :--- |
| 500 μs | 0° | CCW mechanical limit |
| 1500 μs | 135° | Neutral / standing stance |
| 2500 μs | 270° | CW mechanical limit |

Calibrate the exact neutral tick for each hip after installation by running `python3 scripts/set_motor_angle.py` (adapted for BLS) and noting the pulse width where the robot stands level.

---

## 3. Wheel Motors & Driver (Arduino Uno R3 Control)

The wheel motors (JGB-520 12V 550 RPM) are driven by a motor driver controlled directly by the **Arduino Uno R3** (instead of the Raspberry Pi directly). This offloads the high-frequency LQR control loops, encoder interrupts, and real-time motor updates to the Arduino's dedicated microcontroller.

### Drive Module to Arduino Pin Connections
Based on the motor driver's mapping:

| Drive Module Connection | Arduino Uno Pin | Function / Type |
| :--- | :--- | :--- |
| **AIN1** | **Pin 9** | Motor A (Left) Direction Control 1 |
| **AIN2** | **Pin 10** | Motor A (Left) Direction Control 2 (PWM) |
| **BIN1** | **Pin 5** | Motor B (Right) Direction Control 1 (PWM) |
| **BIN2** | **Pin 6** | Motor B (Right) Direction Control 2 (PWM) |
| **E2A** (Encoder 2 Ch A) | **Pin 7** | Motor 2 Encoder Interrupt |
| **E2B** (Encoder 2 Ch B) | **Pin 2** | Motor 2 Encoder Direction |
| **E1A** (Encoder 1 Ch A) | **Pin 8** | Motor 1 Encoder Interrupt |
| **E1B** (Encoder 1 Ch B) | **Pin 4** | Motor 1 Encoder Direction |
| **ADC** (Current/Volt Sensing) | **Pin A0** (Moved from A5) | Analog ADC Input |
| **GND** | **GND** | Reference Ground |

---

## 4. Arduino Uno R3: IMU & Raspberry Pi Interfaces

To balance the robot, the Arduino reads high-speed data from the 9-axis IMU, calculates LQR motor commands, and communicates with the Raspberry Pi for high-level instructions (e.g., path planning, jump triggers).

### A. 9-Axis IMU (6-Axis Config) to Arduino Uno R3
The IMU (e.g. MPU-6050 / MPU-9250 / LSM9DS1) uses **I2C communication** to transfer accelerations and gyroscopic rates to the Arduino.

> [!CAUTION]
> **CRITICAL HARDWARE CONFLICT ON PIN A5**
> On the Arduino Uno R3, the SCL (I2C Clock) is hardwired to **Pin A5** and the SDA (I2C Data) is hardwired to **Pin A4**. 
> **You must move your ADC connection from A5 to A0** (or A1, A2, A3) to prevent crashing the I2C bus!

Once the ADC is relocated, connect the IMU as follows:

| IMU Connection | Arduino Uno R3 Pin | Function |
| :--- | :--- | :--- |
| **VCC** | **3.3V** or **5V** | Power (match your breakout board's requirements) |
| **GND** | **GND** | Common Ground |
| **SDA** | **Pin A4** (or dedicated SDA next to AREF) | I2C Data |
| **SCL** | **Pin A5** (or dedicated SCL next to AREF) | I2C Clock |

### B. Raspberry Pi to Arduino Uno R3 High-Level Interface
To coordinate high-level behaviors while keeping the hardware simple and safe, connect the Arduino Uno R3 to the Raspberry Pi using a **Standard USB-A to USB-B Cable**.

```
+──────────────────────+       Standard USB Cable       +──────────────────────+
|                      | ============================== |                      |
|     Raspberry Pi     | <────────────────────────────> |    Arduino Uno R3    |
|                      |     Power & Serial Telemetry   |                      |
+──────────────────────+                                +──────────────────────+
```

#### Why USB is the standard for this architecture:
1. **Safety (No Logic Mismatch):** The Raspberry Pi operates at **3.3V logic level**, whereas the Arduino Uno runs at **5V logic level**. Connecting their TX/RX hardware pins directly would **permanently damage the Pi's GPIO pins** unless logic-level shifters were added. USB serial bypasses this issue entirely.
2. **Robust Telemetry:** Registered as a standard virtual COM port (`/dev/ttyACM0` or `/dev/ttyUSB0`) on the Pi. It is easy to write serial handlers in Python using `pyserial` and receive state data at high frequencies.
3. **Power Delivery:** The Pi's USB port supplies stable 5V power directly to the Arduino, eliminating the need for a separate Arduino power regulator.

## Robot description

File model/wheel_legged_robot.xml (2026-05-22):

<mujoco model="wheel_legged_5bar">
  <compiler angle="radian" meshdir="meshes" autolimits="true"/>

  <option timestep="0.002" gravity="0 0 -9.81" integrator="implicitfast" solver="Newton" iterations="100" tolerance="1e-10"/>

  <size njmax="500" nconmax="200"/>

  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

  <default>
    <default class="link">
      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
      <joint type="hinge" axis="1 0 0" damping="0.05" armature="0.001"/>
    </default>
    <default class="wheel">
      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
      <joint type="hinge" axis="1 0 0" damping="0.02" armature="0.005"/>
    </default>
    <default class="hip_actuator">
      <position kp="80" kv="4" ctrlrange="-2.0 2.0" forcerange="-30 30"/>
    </default>
    <default class="wheel_actuator">
      <motor ctrlrange="-8 8" forcerange="-8 8"/>
    </default>
  </default>

  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

  <worldbody>
    <light name="top" pos="0 0 3" dir="0 0 -1" diffuse="0.7 0.7 0.7"/>
    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

    <body name="chassis" pos="0 0 0.389" childclass="link">
      <freejoint name="root"/>
      <inertial pos="0 0 0.105" mass="3.5" diaginertia="0.04 0.06 0.05"/>
      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
      <body name="UL_R" pos="0.11200 0.00000 0.10500" quat="0.903805 -0.427945 0.000000 0.000000">
        <inertial pos="0 0.147 0" mass="0.30" diaginertia="0.003 0.0003 0.003"/>
        <joint name="hip_UL_R" pos="0 0 0" range="-120 120" ref="0"/>
        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

        <body name="LA_R" pos="0.02900 0.29400 0.00000" quat="0.777015 -0.629482 0.000000 0.000000">
          <inertial pos="0 0.149 0" mass="0.25" diaginertia="0.003 0.0003 0.003"/>
          <joint name="knee_KR_R" pos="0 0 0" range="-160 160" ref="0"/>
          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
        </body>
      </body>

      <body name="US_R" pos="0.12800 0.00000 0.10500" quat="0.514655 -0.857397 0.000000 0.000000">
        <inertial pos="0 0.100 0" mass="0.20" diaginertia="0.001 0.0002 0.001"/>
        <joint name="hip_US_R" pos="0 0 0" range="-120 120" ref="0"/>
        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

        <body name="LB_R" pos="0.02500 0.20100 0.00000" quat="0.918639 0.395099 0.000000 0.000000">
          <inertial pos="0 0.149 0" mass="0.25" diaginertia="0.003 0.0003 0.003"/>
          <joint name="knee_KF_R" pos="0 0 0" range="-160 160" ref="0"/>
          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

          <body name="wheel_R" pos="-0.01200 0.29800 0.00000" quat="1 0 0 0">
            <inertial pos="0 0 0" mass="0.20" diaginertia="0.00012 0.00018 0.00012"/>
            <joint name="wheel_R_drive" type="hinge" axis="1 0 0" damping="0.02" armature="0.005"/>
            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
          </body>
        </body>
      </body>

      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
      <body name="UL_L" pos="-0.11200 0.00000 0.10500" quat="0.903805 -0.427945 0.000000 0.000000">
        <inertial pos="0 0.147 0" mass="0.30" diaginertia="0.003 0.0003 0.003"/>
        <joint name="hip_UL_L" pos="0 0 0" range="-120 120" ref="0"/>
        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

        <body name="LA_L" pos="-0.02900 0.29400 0.00000" quat="0.777015 -0.629482 0.000000 0.000000">
          <inertial pos="0 0.149 0" mass="0.25" diaginertia="0.003 0.0003 0.003"/>
          <joint name="knee_KR_L" pos="0 0 0" range="-160 160" ref="0"/>
          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
        </body>
      </body>

      <body name="US_L" pos="-0.12800 0.00000 0.10500" quat="0.514655 -0.857397 0.000000 0.000000">
        <inertial pos="0 0.100 0" mass="0.20" diaginertia="0.001 0.0002 0.001"/>
        <joint name="hip_US_L" pos="0 0 0" range="-120 120" ref="0"/>
        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

        <body name="LB_L" pos="-0.02500 0.20100 0.00000" quat="0.918639 0.395099 0.000000 0.000000">
          <inertial pos="0 0.149 0" mass="0.25" diaginertia="0.003 0.0003 0.003"/>
          <joint name="knee_KF_L" pos="0 0 0" range="-160 160" ref="0"/>
          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

          <body name="wheel_L" pos="0.01200 0.29800 0.00000" quat="0 0 0 1">
            <inertial pos="0 0 0" mass="0.20" diaginertia="0.00012 0.00018 0.00012"/>
            <joint name="wheel_L_drive" type="hinge" axis="1 0 0" damping="0.02" armature="0.005"/>
            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
          </body>
        </body>
      </body>
    </body>
  </worldbody>

  <equality>
    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
    <connect name="loop_R" site1="foot_LA_R" site2="hub_R" active="true" solref="0.005 1"/>
    <connect name="loop_L" site1="foot_LA_L" site2="hub_L" active="true" solref="0.005 1"/>
    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
    <joint name="couple_R" joint1="hip_US_R" joint2="hip_UL_R" polycoef="0 -1 0 0 0" solref="0.005 1"/>
    <joint name="couple_L" joint1="hip_US_L" joint2="hip_UL_L" polycoef="0 -1 0 0 0" solref="0.005 1"/>
  </equality>

  <actuator>
    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
    <position class="hip_actuator" name="motor_hip_R" joint="hip_UL_R"/>
    <position class="hip_actuator" name="motor_hip_L" joint="hip_UL_L"/>
    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
    <motor class="wheel_actuator" name="motor_wheel_R" joint="wheel_R_drive"/>
    <motor class="wheel_actuator" name="motor_wheel_L" joint="wheel_L_drive"/>
  </actuator>

  <sensor>
    <jointpos name="qp_UL_R" joint="hip_UL_R"/>
    <jointpos name="qp_US_R" joint="hip_US_R"/>
    <jointpos name="qp_UL_L" joint="hip_UL_L"/>
    <jointpos name="qp_US_L" joint="hip_US_L"/>
    <jointvel name="qv_wheel_R" joint="wheel_R_drive"/>
    <jointvel name="qv_wheel_L" joint="wheel_L_drive"/>
    <framepos name="chassis_pos" objtype="body" objname="chassis"/>
    <framequat name="chassis_quat" objtype="body" objname="chassis"/>
    <gyro name="imu_gyro" site="imu_site"/>
    <accelerometer name="imu_acc" site="imu_site"/>
  </sensor>
</mujoco>

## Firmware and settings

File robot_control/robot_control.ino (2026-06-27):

// ================================================================
// JUMPING WHEEL-LEGGED ROBOT — Arduino Uno R3
// UCR MEDDL Lab
// ================================================================
// PIN MAP:
//  D2  - Right encoder B (direction)
//  D4  - Left encoder B (direction)
//  D5~ - AT8236 BIN1  (right motor PWM, Timer 0 OC0B)
//  D6~ - AT8236 BIN2  (right motor PWM, Timer 0 OC0A)
//  D7  - Right encoder A (interrupt via PCINT2)
//  D8  - Left encoder A  (interrupt via PCINT0)
//  D9~ - AT8236 AIN1  (left motor PWM, Timer 1 OC1A)
//  D10~- AT8236 AIN2  (left motor PWM, Timer 1 OC1B)
//  D11~- BLS3355 Right hip servo PWM (bit-banged via Timer 2 ISR)
//  D12 - BLS3355 Left hip servo PWM  (bit-banged via Timer 2 ISR)
//  A4  - MPU6050 SDA (I2C)
//  A5  - MPU6050 SCL (I2C)
// ================================================================
// SERVO NOTE: Servo.h cannot be used — it steals Timer 1, which
//   is needed for analogWrite on D9/D10 (motor control).
//   Instead, Timer 2 CTC ISR generates 50 Hz servo pulses on D12/D11.
//   ISR tick: 20 μs  (prescaler=8, OCR2A=39)
//   Pulse range: 500–2500 μs (25–125 ticks), frame: 1000 ticks = 20 ms
// ================================================================
// REQUIRED LIBRARIES:
//   1. Wire.h — built-in (I2C for MPU6050)
// ================================================================
// BEFORE FIRST RUN:
//   - Calibrate BALANCE_OFFSET so robot stands straight
//   - Set SERVO_BOOT_LEFT_US / SERVO_BOOT_RIGHT_US from the calibrated
//     stance (must match bls.left/right default_us in config/robot.yaml)
// ================================================================

#include <Wire.h>

// ── TUNING PARAMETERS ─────────────────────────────────────────
// LQR state-feedback gains from scripts/compute_lqr_gain.py.
// State x = [posErr (m), velErr (m/s), pitch (rad), pitchRate (rad/s)]
// Output: tau (N·m) = Kx·posErr + Kv·velErr + Kp·pitch + Kd·pitchRate
// PWM = Ks · tau  (Ks in PWM per N·m — the main hardware-tuning knob)
// Signs: Kp,Kd > 0 (lean forward → drive forward); Kx,Kv < 0 (resist drift)
float Kx =  -63.2456;   // position-error gain  (N·m/m)
float Kv =  -71.8334;   // velocity-error gain  (N·m per m/s)
float Kp =  345.3348;   // pitch gain           (N·m/rad)
float Kd =   82.7683;   // pitch-rate gain      (N·m per rad/s)
float Ks =    3.0;      // torque→PWM scalar (PWM per N·m) — TUNE ON HARDWARE.
                        // Lowered from 7.8: at 7.8 the output saturated at only
                        // ~5.4° tilt (bang-bang, overshoots). 3.0 saturates near
                        // ~14°, keeping the LQR in its linear/damped range.

// Tilt offset (degrees) — tune so robot stands upright without moving
// Positive = robot leans forward, Negative = leans back
float balanceOffset = 1.4;

// Max robot speed from controller (motor PWM units 0-255)
#define MAX_SPEED      180
#define MAX_TURN       130   // raised from 80 — gives enough differential to overcome motor stiction

// Fall detection — stop motors if tilted too far
#define FALL_ANGLE      35.0   // degrees

// Encoder pulses per revolution (full quadrature)
// JGB37-520: typically 11 pulses/rev on motor shaft x gear ratio
// Measure by spinning wheel one full rotation and counting pulses
#define ENC_PPR         660    // adjust after measuring

// Wheel circumference (metres)
#define WHEEL_CIRC      0.204  // π × 0.065m diameter

// Complementary filter coefficient (0.95-0.99)
#define CF_ALPHA        0.98

// Motor deadband compensation (stiction threshold)
#define MOTOR_DEADBAND  25

// MPU6050 I2C address
#define MPU_ADDR        0x68

// Loop timing
#define LOOP_HZ         200    // balance loop frequency
#define LOOP_US         (1000000 / LOOP_HZ)

// ── PIN DEFINITIONS ───────────────────────────────────────────────
#define PIN_ENC_L_A     8      // PCINT0 (Port B)
#define PIN_ENC_L_B     4
#define PIN_ENC_R_A     7      // PCINT2 (Port D)
#define PIN_ENC_R_B     2

#define PIN_AIN1        9      // Left Motor PWM Direction 1 (OC1A / Timer 1)
#define PIN_AIN2        10     // Left Motor PWM Direction 2 (OC1B / Timer 1)
#define PIN_BIN1        5      // Right Motor PWM Direction 1 (OC0B / Timer 0)
#define PIN_BIN2        6      // Right Motor PWM Direction 2 (OC0A / Timer 0)

#define SERVO_PIN_LEFT  12     // BLS3355 left hip  (bit-banged in Timer 2 ISR)
#define SERVO_PIN_RIGHT 11     // BLS3355 right hip (bit-banged in Timer 2 ISR)

// ── SERVO PWM (Timer 2 ISR, 20 μs tick) ───────────────────────────
// Tick period: (OCR2A+1) * prescaler / F_CPU = 40 * 8 / 16e6 = 20 μs
// Servo frame: 1000 ticks = 20 ms (50 Hz)
// Pulse range: 25 ticks (500 μs) to 125 ticks (2500 μs)
#define SERVO_MIN_US      500
#define SERVO_MAX_US      2500
#define SERVO_NEUTRAL_US  1500
#define SERVO_FRAME_TICKS 1000   // 20 ms

// Boot/default stance — the pose the hips drive to at power-on and on ESTOP.
// Keep in sync with bls.left/right default_us in config/robot.yaml.
// Observed on hardware: the mirrored pulse pair (1540/1460) moved the legs
// in OPPOSITE directions (left up, right down), which means the same pulse
// offset moves both legs the SAME way. No mirroring about neutral — both
// hips get the same pulse.
// 1580 = both legs +10.8° (≈10° target — nearest 20 μs tick). Lower stance.
#define SERVO_BOOT_LEFT_US   1540   // left leg  ≈+10° (lower stance)
#define SERVO_BOOT_RIGHT_US  1540   // right leg ≈+10° (same pulse, no mirroring)

// ── TEMPORARY HIP RAISE/LOWER TEST ────────────────────────────
// Set SERVO_TEST_MODE to 1 to oscillate both hips up/down about the
// standing stance (verifies the servos lift and lower the body under
// load before enabling LQR). Set to 0 to restore normal operation
// (robot just holds the standing stance). Kept the ±20° sweep settings
// below so it can be re-enabled instantly.
#define SERVO_TEST_MODE      0
#define SERVO_TEST_CENTER_US SERVO_BOOT_LEFT_US  // oscillate about standing stance (1580)
#define SERVO_TEST_AMP_US    148   // ≈20° swing  (~7.4 µs/deg on a 270° servo)
#define SERVO_TEST_PERIOD_MS 1000  // one full up→down→up cycle (ms) — 2× faster

// Pulse widths commanded by RPi (μs). Written from main loop, read by ISR.
// uint16_t writes are NOT atomic on AVR — always update with cli/sei guard.
volatile uint16_t g_servoLeftUs  = SERVO_BOOT_LEFT_US;
volatile uint16_t g_servoRightUs = SERVO_BOOT_RIGHT_US;

ISR(TIMER2_COMPA_vect) {
  static uint16_t tick     = 0;
  static uint16_t leftEnd  = (SERVO_BOOT_LEFT_US + 10) / 20;
  static uint16_t rightEnd = (SERVO_BOOT_LEFT_US + 10) / 20 + (SERVO_BOOT_RIGHT_US + 10) / 20;

  if (tick == 0) {
    // Snapshot pulse widths at frame start (convert μs → 20-μs ticks).
    // Round to NEAREST tick (+10 before /20): plain truncation rounds both
    // pulses down in μs, which is asymmetric about the 1500 μs neutral and
    // un-mirrors a (1500+x, 1500−x) hip pair by up to a full 20 μs tick.
    leftEnd  = (g_servoLeftUs  + 10) / 20;
    rightEnd = leftEnd + (g_servoRightUs + 10) / 20;
    digitalWrite(SERVO_PIN_LEFT, HIGH);
  }
  if (tick == leftEnd) {
    digitalWrite(SERVO_PIN_LEFT,  LOW);
    digitalWrite(SERVO_PIN_RIGHT, HIGH);
  }
  if (tick == rightEnd) {
    digitalWrite(SERVO_PIN_RIGHT, LOW);
  }

  if (++tick >= SERVO_FRAME_TICKS) tick = 0;
}

// Encoder counts (volatile — modified in ISR)
volatile long encL = 0;
volatile long encR = 0;

// MPU6050 raw values
int16_t ax, ay, az, gx, gy, gz;

// Balance state
float tiltAngle    = 0.0;   // degrees, 0 = vertical
float tiltRate     = 0.0;   // degrees/sec
float speedL       = 0.0;   // m/s left wheel
float speedR       = 0.0;   // m/s right wheel
float speedAvg     = 0.0;   // average forward speed
float posErr       = 0.0;   // integral of velocity error = position-error state x[0]
long  prevEncL     = 0;
long  prevEncR     = 0;

float gyroBiasY         = 0.0; // Gyro zero-rate bias on Y-axis
float prevSpeedAvg      = 0.0; // Last avg speed for derivative tracking
float axleAccel         = 0.0; // Estimated linear acceleration (m/s^2)
float filteredAxleAccel = 0.0; // Low-pass filtered axle acceleration

// Controller commands (received from RPi over serial)
int   cmdSpeed     = 0;     // -255 to 255 (forward/backward)
int   cmdTurn      = 0;     // -255 to 255 (left/right)
bool  cmdJump      = false;

// Timed impulse disturbance variables
unsigned long impulseStartMs = 0;
unsigned long impulseDurationMs = 0;
int impulseSpeed = 0;
bool impulseActive = false;

// State flags
bool  fallen       = false;
bool  jumping      = false;
unsigned long jumpStartMs = 0;

// Arming — robot stays idle until RPi sends "START"
bool  running      = false;

// Timing
unsigned long prevLoopUs   = 0;
unsigned long prevSpeedMs  = 0;
unsigned long prevSerialMs = 0;
unsigned long prevReadyMs  = 0;

// ── ENCODER ISRs (Hardware Pin Change Interrupts) ─────────────
// Left Encoder ISR triggers on Pin 8 change (Port B, PCINT0)
ISR(PCINT0_vect) {
  static uint8_t lastStateL = LOW;
  uint8_t stateA = digitalRead(PIN_ENC_L_A);
  if (stateA != lastStateL) {
    lastStateL = stateA;
    if (stateA == digitalRead(PIN_ENC_L_B)) {
      encL++;
    } else {
      encL--;
    }
  }
}

// Right Encoder ISR triggers on Pin 7 change (Port D, PCINT2)
ISR(PCINT2_vect) {
  static uint8_t lastStateR = LOW;
  uint8_t stateA = digitalRead(PIN_ENC_R_A);
  if (stateA != lastStateR) {
    lastStateR = stateA;
    if (stateA == digitalRead(PIN_ENC_R_B)) {
      encR--; // Mirrored right wheel rotation direction
    } else {
      encR++;
    }
  }
}


// ── MPU6050 FUNCTIONS ─────────────────────────────────────────
void mpuInit() {
  Wire.begin();
  Wire.setClock(400000);  // 400kHz fast mode

  Wire.beginTransmission(MPU_ADDR);
  Wire.write(0x6B);  // PWR_MGMT_1
  Wire.write(0x00);  // Wake up
  Wire.endTransmission();

  Wire.beginTransmission(MPU_ADDR);
  Wire.write(0x1B);  // GYRO_CONFIG
  Wire.write(0x00);  // ±250°/s range
  Wire.endTransmission();

  Wire.beginTransmission(MPU_ADDR);
  Wire.write(0x1C);  // ACCEL_CONFIG
  Wire.write(0x00);  // ±2g range
  Wire.endTransmission();

  // Digital low-pass filter — 44Hz
  Wire.beginTransmission(MPU_ADDR);
  Wire.write(0x1A);  // CONFIG
  Wire.write(0x03);
  Wire.endTransmission();
}

void mpuRead() {
  Wire.beginTransmission(MPU_ADDR);
  Wire.write(0x3B);  // ACCEL_XOUT_H
  Wire.endTransmission(false);
  Wire.requestFrom(MPU_ADDR, 14, true);

  ax = (Wire.read() << 8) | Wire.read();
  ay = (Wire.read() << 8) | Wire.read();
  az = (Wire.read() << 8) | Wire.read();
  Wire.read(); Wire.read();  // skip temperature
  gx = (Wire.read() << 8) | Wire.read();
  gy = (Wire.read() << 8) | Wire.read();
  gz = (Wire.read() << 8) | Wire.read();
}

// ── ANGLE CALCULATION (Complementary Filter) ──────────────────
// Returns angle in degrees. 0 = upright, + = leaning forward
void updateAngle(float dt) {
  // Compute axle linear acceleration (speedAvg derivative)
  axleAccel = (speedAvg - prevSpeedAvg) / dt;
  prevSpeedAvg = speedAvg;

  // Low-pass filter to reject high-frequency encoder noise
  filteredAxleAccel = 0.8 * filteredAxleAccel + 0.2 * axleAccel;

  // Convert raw ax to g's, subtract axle acceleration, convert back
  float ax_g = (float)ax / 16384.0;
  float ax_compensated = ax_g - (filteredAxleAccel / 9.81);

  // Pitch (fall) angle calculation (rotation about Y axis)
  float accelAngle = atan2(ax_compensated, (float)az / 16384.0) * 57.2958;

  // Gyro rate (Y-axis rotation rate in deg/s), corrected with calibrated bias
  tiltRate = (float)(gy - gyroBiasY) / 131.0;

  // Complementary filter
  tiltAngle = CF_ALPHA * (tiltAngle + tiltRate * dt) +
              (1.0 - CF_ALPHA) * accelAngle;
}

// ── MOTOR CONTROL (Yahboom YB-MNT03-v1.0 TB6612 Dual PWM Mode) ──
int applyDeadband(int pwm) {
  if (pwm > 0) return map(pwm, 0, 255, MOTOR_DEADBAND, 255);
  if (pwm < 0) return map(pwm, -255, 0, -255, -MOTOR_DEADBAND);
  return 0;
}

void setMotors(int leftPWM, int rightPWM) {
  leftPWM = applyDeadband(leftPWM);
  rightPWM = applyDeadband(rightPWM);

  // Left motor (Channel A) — Pin 9 (AIN1) and Pin 10 (AIN2)
  if (leftPWM > 0) {
    digitalWrite(PIN_AIN1, LOW);
    analogWrite(PIN_AIN2, constrain(leftPWM, 0, 255));
  } else if (leftPWM < 0) {
    analogWrite(PIN_AIN1, constrain(-leftPWM, 0, 255));
    digitalWrite(PIN_AIN2, LOW);
  } else {
    digitalWrite(PIN_AIN1, LOW);
    digitalWrite(PIN_AIN2, LOW);
  }

  // Right motor (Channel B) — Pin 5 (BIN1) and Pin 6 (BIN2)
  if (rightPWM > 0) {
    analogWrite(PIN_BIN1, constrain(rightPWM, 0, 255));
    digitalWrite(PIN_BIN2, LOW);
  } else if (rightPWM < 0) {
    digitalWrite(PIN_BIN1, LOW);
    analogWrite(PIN_BIN2, constrain(-rightPWM, 0, 255));
  } else {
    digitalWrite(PIN_BIN1, LOW);
    digitalWrite(PIN_BIN2, LOW);
  }
}

void stopMotors() {
  digitalWrite(PIN_AIN1, LOW);
  digitalWrite(PIN_AIN2, LOW);
  digitalWrite(PIN_BIN1, LOW);
  digitalWrite(PIN_BIN2, LOW);
}

// ── SPEED MEASUREMENT ─────────────────────────────────────────
void updateSpeed(float dt) {
  long dL = encL - prevEncL;
  long dR = encR - prevEncR;
  prevEncL = encL;
  prevEncR = encR;

  // Convert pulses to m/s
  speedL = ((float)dL / ENC_PPR) * WHEEL_CIRC / dt;
  speedR = ((float)dR / ENC_PPR) * WHEEL_CIRC / dt;
  speedAvg = (speedL + speedR) / 2.0;
}

// ── LQR BALANCE CONTROLLER ────────────────────────────────────
// Full-state feedback: x = [posErr (m), velErr (m/s), pitch (rad), pitchRate (rad/s)]
// tau (N·m) = K · x  →  PWM = Ks · tau
// Signs match the lean-to-catch convention: Kp,Kd > 0; Kx,Kv < 0.
int balanceControl(float dt) {
  // Velocity setpoint from controller (-255..255 → ±1.5 m/s)
  float vTarget = (float)cmdSpeed / 255.0 * 1.5;
  float velErr  = speedAvg - vTarget;

  // Position-error state = integral of velocity error, with anti-windup clamp
  if (cmdSpeed != 0) {
    posErr *= 0.95; // decay the accumulator during active driving
  } else {
    posErr += velErr * dt;
    posErr  = constrain(posErr, -0.5, 0.5);
  }

  // Angle states in SI radians so the offline-solved K applies verbatim.
  // Sign NEGATED: the Y-axis IMU convention reads pitch opposite to the
  // wheel/motor frame, so a forward lean must command a forward (catching)
  // drive. pitch and pitchRate flip together so Kd stays damping.
  float pitch     = -(tiltAngle - balanceOffset) * 0.0174533;  // deg → rad
  float pitchRate = -tiltRate                    * 0.0174533;  // deg/s → rad/s

  // LQR state feedback → wheel torque (N·m), scaled to motor PWM
  float tau  = Kx * posErr + Kv * velErr + Kp * pitch + Kd * pitchRate;
  int output = (int)(Ks * tau);
  return constrain(output, -255, 255);
}

// ── JUMP FLIGHT DETECTION / TIMING ────────────────────────────
// The jump height sequence is coordinated directly by the high-level
// Python scripts on the RPi. The Arduino simply tracks the jumping state.
void startJump() {
  if (jumping) return;
  jumping = true;
  jumpStartMs = millis();
}

void updateJump() {
  if (!jumping) return;
  unsigned long elapsed = millis() - jumpStartMs;

  // Emulate jump duration safety window (e.g. 1.4 seconds total)
  if (elapsed >= 1400) {
    jumping = false;
  }
}

// ── TIMED IMPULSE DISTURBANCE FUNCTIONS ───────────────────────
void startImpulse(int speed, int durationMs) {
  impulseSpeed = constrain(speed, -255, 255);
  impulseDurationMs = durationMs;
  impulseStartMs = millis();
  impulseActive = true;
  cmdSpeed = impulseSpeed; // apply speed setpoint immediately
}

void updateImpulse() {
  if (!impulseActive) return;
  if (millis() - impulseStartMs >= impulseDurationMs) {
    impulseActive = false;
    cmdSpeed = 0; // reset speed setpoint to zero
  }
}

// ── SERIAL COMMAND PARSER (C-string non-allocating process) ──
void processCommand(char* buf) {
  if (strcmp(buf, "START") == 0) {
    posErr = 0.0;
    fallen = false;
    jumping = false;
    cmdSpeed = 0;
    cmdTurn = 0;
    cmdJump = false;
    running = true;
    Serial.println("RUNNING");
  } else if (strcmp(buf, "ESTOP") == 0) {
    running = false;
    jumping = false;
    cmdJump = false;
    impulseActive = false;
    posErr = 0.0;
    stopMotors();
    cli();
    g_servoLeftUs  = SERVO_BOOT_LEFT_US;
    g_servoRightUs = SERVO_BOOT_RIGHT_US;
    sei();
    Serial.println("STOPPED");
  } else if (strncmp(buf, "CMD:", 4) == 0) {
    int spd, turn, jmp;
    if (sscanf(buf + 4, "%d:%d:%d", &spd, &turn, &jmp) == 3) {
      cmdSpeed = constrain(spd, -255, 255);
      cmdTurn = constrain(turn, -255, 255);
      if (jmp == 1 && !cmdJump) {
        cmdJump = true;
        startJump();
      } else if (jmp == 0) {
        cmdJump = false;
      }
    }
  } else if (strncmp(buf, "IMP:", 4) == 0) {
    int spd, dur;
    if (sscanf(buf + 4, "%d:%d", &spd, &dur) == 2) {
      startImpulse(spd, dur);
    }
  } else if (strncmp(buf, "SRV:", 4) == 0) {
    int id, us;
    if (sscanf(buf + 4, "%d:%d", &id, &us) == 2) {
      us = constrain(us, SERVO_MIN_US, SERVO_MAX_US);
      cli();
      if      (id == 1) g_servoLeftUs  = (uint16_t)us;
      else if (id == 2) g_servoRightUs = (uint16_t)us;
      sei();
    }
  } else if (strncmp(buf, "TUN:", 4) == 0) {
    float kx_val, kv_val, kp_val, kd_val, ks_val, bo_val;
    if (sscanf(buf + 4, "%f:%f:%f:%f:%f:%f", &kx_val, &kv_val, &kp_val, &kd_val, &ks_val, &bo_val) == 6) {
      Kx = kx_val;
      Kv = kv_val;
      Kp = kp_val;
      Kd = kd_val;
      Ks = ks_val;
      balanceOffset = bo_val;
      
      Serial.print("TUN_ACK:");
      Serial.print(Kx, 4); Serial.print(":");
      Serial.print(Kv, 4); Serial.print(":");
      Serial.print(Kp, 4); Serial.print(":");
      Serial.print(Kd, 4); Serial.print(":");
      Serial.print(Ks, 4); Serial.print(":");
      Serial.println(balanceOffset, 4);
    }
  }
}

void parseSerial() {
  static char serialBuffer[64];
  static byte idx = 0;
  
  while (Serial.available() > 0) {
    char c = Serial.read();
    if (c == '\n') {
      serialBuffer[idx] = '\0';
      processCommand(serialBuffer);
      idx = 0;
    } else if (idx < sizeof(serialBuffer) - 1) {
      if (c != '\r') {
        serialBuffer[idx++] = c;
      }
    }
  }
}
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
void loop() {
  unsigned long now = micros();
  if ((now - prevLoopUs) < LOOP_US) return;  // Rate limit

  float dt = (now - prevLoopUs) / 1000000.0;
  prevLoopUs = now;
  dt = constrain(dt, 0.001, 0.05);  // Safety clamp

  // ── TEMPORARY: hip raise/lower test ─────────────────────────
  // Smoothly sweeps both hips ±5° about the standing stance so we can
  // watch the body rise and lower and confirm the servos carry the
  // load before switching to LQR. Wheels stay off; serial/LQR skipped.
#if SERVO_TEST_MODE
  float ph    = (millis() % SERVO_TEST_PERIOD_MS) / (float)SERVO_TEST_PERIOD_MS;
  float delta = SERVO_TEST_AMP_US * sin(ph * 2.0 * PI);
  // Hips are mirror-mounted: an EQUAL pulse spins both servos the same way,
  // lifting one leg and dropping the other (body rocks side-to-side).
  // Mirror the right pulse about the stance (left +delta, right -delta) so
  // the servos counter-rotate and both legs raise/lower the body together.
  // If the body still moves the wrong way, swap the +/- signs below.
  uint16_t leftPulse  = (uint16_t)constrain(SERVO_TEST_CENTER_US + delta, SERVO_MIN_US, SERVO_MAX_US);
  uint16_t rightPulse = (uint16_t)constrain(SERVO_TEST_CENTER_US - delta, SERVO_MIN_US, SERVO_MAX_US);
  cli();
  g_servoLeftUs  = leftPulse;
  g_servoRightUs = rightPulse;
  sei();
  stopMotors();   // keep wheels off — hips only
  return;         // skip serial + balance loop while testing
#endif

  // Always parse serial so START / ESTOP are responsive
  parseSerial();

  // Hold idle until armed by RPi. Motors stay OFF, but we still read the IMU
  // and stream telemetry so the calibration / IMU-monitor tools work safely
  // while DISARMED (no wheels driving). Speed state is kept fresh so arming
  // doesn't produce a stale velocity spike.
  if (!running) {
    stopMotors();
    impulseActive = false;
    mpuRead();
    updateAngle(dt);
    updateSpeed(dt);
    if ((millis() - prevSerialMs) >= 50) {
      sendTelemetry();
      prevSerialMs = millis();
    }
    if ((millis() - prevReadyMs) >= 1000) {
      Serial.println("READY");
      prevReadyMs = millis();
    }
    return;
  }

  // 1. Read IMU and update angle
  mpuRead();
  updateAngle(dt);

  // 2. Update wheel speed
  updateSpeed(dt);

  // 3. Check for fall
  if (abs(tiltAngle - balanceOffset) > FALL_ANGLE) {
    fallen = true;
    stopMotors();
    posErr = 0.0;
  } else {
    fallen = false;
  }

  // 4. Update jump state machine
  updateJump();

  // Update timed impulse disturbance
  updateImpulse();

  // 5. Compute and apply motor control (only if not fallen)
  if (!fallen) {
    int basePWM = balanceControl(dt);

    // Turn: differential — left faster = turn right
    int turnPWM = map(cmdTurn, -255, 255, -MAX_TURN, MAX_TURN);

    int leftPWM  = basePWM - turnPWM;
    int rightPWM = basePWM + turnPWM;

    leftPWM  = constrain(leftPWM,  -255, 255);
    rightPWM = constrain(rightPWM, -255, 255);

    setMotors(leftPWM, rightPWM);
  }

  // 6. Send telemetry every 50ms
  if ((millis() - prevSerialMs) >= 50) {
    sendTelemetry();
    prevSerialMs = millis();
  }
}

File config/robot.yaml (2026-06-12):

# =========================================================================
#             JUMPING WHEEL-LEGGED ROBOT — CONFIGURATION SCHEMA
#                         Developed for UCR MEDDL Lab
# =========================================================================

# ── ARDUINO UNO R3 TELEMETRY LINK ────────────────────────────────────────
# Coordinates wheel control LQR loops, encoder interrupts, and MPU6050 feed.
arduino:
  device_linux: /dev/ttyACM0
  device_win: COM1
  device_mac: /dev/tty.usbserial
  baudrate: 115200

# ── BLS3355 BRUSHLESS HIP JOINTS ─────────────────────────────────────────
# BLS3355: 61 kg·cm, 6.0–8.4 V (2S LiPo). These are standard RC PWM servos,
# NOT serial-bus servos — the Arduino generates 50 Hz pulses on D12/D11 and the
# Pi commands them with SRV:<id>:<pulse_us> over the 115200-baud serial link.
# IMPORTANT: max supply voltage is 8.4 V — do NOT run on 3S LiPo (12 V).
bls:
  # The hips share the Arduino serial link (see the arduino: block above) —
  # there is no dedicated servo bus, so no device/baudrate keys here.

  # Individual joint parameters
  # default_us: stance pulse width in μs (500–2500, 1500 = neutral).
  # Calibrate by hand after installation, then mirror the calibrated values
  # into SERVO_BOOT_LEFT_US / SERVO_BOOT_RIGHT_US in robot_control.ino so
  # the Arduino boots into the same stance.
  # Observed on hardware: a mirrored pulse pair (1540/1460) moved the legs in
  # OPPOSITE directions, so the same pulse offset moves both legs the SAME
  # way. Both hips get the same pulse and the same direction multiplier.
  # 1580 = both legs ≈+10.8° (≈10° target, nearest firmware tick) — lower stance.
  left:
    id: 1
    default_us: 1540     # left leg ≈+10° (lower stance) — matches SERVO_BOOT_LEFT_US
    offset_rad: 0.0
    direction: 1
    min_rad: -1.5708
    max_rad: 1.5708
  right:
    id: 2
    default_us: 1540     # right leg ≈+10° (lower stance) — matches SERVO_BOOT_RIGHT_US
    offset_rad: 0.0
    direction: 1
    min_rad: -1.5708
    max_rad: 1.5708

# ── DC DRIVE WHEELS (JGB-520 MOTORS) ────────────────────────────────────
# Governs wheel geometry and encoder configurations for speed averaging.
wheels:
  encoder_ppr: 660
  wheel_circumference_m: 0.204   # π × 0.065 m diameter (matches firmware WHEEL_CIRC)
  max_speed_pwm: 180
  max_turn_pwm: 80

  # Individual wheel configurations (aligned with physical drivers)
  left:
    id: 1                  # Motor 1 / Channel A
    direction: 1           # Direction multiplier (1 = normal)
  right:
    id: 2                  # Motor 2 / Channel B
    direction: -1          # Direction multiplier (-1 = mirrored mounting)

# ── BALANCE DYNAMICS (offline LQR gain design) ───────────────────────────
# Used by scripts/compute_lqr_gain.py to solve the Riccati equation and
# write config/lqr_gains.json.  Re-run compute_lqr_gain.py after any
# change to robot mass, geometry, or cost weights.
physical:
  total_mass_kg:       2.5      # whole robot incl. all components
  wheel_mass_kg:       0.10     # per wheel (drive motors live in chassis -> light wheels)
  wheel_radius_m:      0.0325   # 65 mm diameter (firmware WHEEL_CIRC = 0.204 m)
  com_height_m:        0.58     # axle -> chassis/COM, FULLY-EXTENDED stance (measured)
  pitch_inertia_kgm2:  0.012    # chassis box about its own COM (small vs m·L²)

  # LQR cost weights for state [x, xdot, pitch, pitch_rate] and input u
  q_weights: [80.0, 20.0, 400.0, 25.0]
  r_weight:  0.02

  # torque (N·m) -> motor PWM (0–255). Seeded so the LQR pitch gain reproduces
  # the known-good PID kpAngle≈45 PWM/deg response. TUNE THIS ON HARDWARE.
  torque_to_pwm: 7.8

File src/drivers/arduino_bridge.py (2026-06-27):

"""
ArduinoBridge — Resilient, thread-safe serial communication driver for the Jumping Robot.
Manages a single shared serial connection to the Arduino Uno R3, handles background 
telemetry updates, auto-detects USB ports, and recovers from cable disconnections.
"""

import os
import sys
import time
import serial
import serial.tools.list_ports
import threading
from typing import Dict, Optional, Tuple

class ArduinoBridge:
    """
    Manages USB serial communication between Raspberry Pi and Arduino.
    Handles telemetry read loop (background thread) and thread-safe command writes.
    """
    def __init__(self, port: Optional[str] = None, baudrate: int = 115200):
        self.port = port
        self.baudrate = baudrate
        self.ser: Optional[serial.Serial] = None
        self.running = False
        self.thread: Optional[threading.Thread] = None

        # Lock for telemetry state access
        self._state_lock = threading.Lock()
        
        # Lock to ensure only one thread writes to the serial port at a time
        self._write_lock = threading.Lock()

        # Telemetry State Variables
        self._tilt_angle = 0.0
        self._wheel_speed = 0.0
        self._fallen = False
        self._jumping = False
        self._last_received = 0.0
        self._is_connected = False

        # Tuning State Variables (acknowledged by Arduino) — LQR gains
        self._ack_kx = 0.0
        self._ack_kv = 0.0
        self._ack_kp = 0.0
        self._ack_kd = 0.0
        self._ack_ks = 0.0
        self._ack_balance_offset = 0.0

        # IMU raw axes (in physical units: g and °/s)
        self._accel_x = 0.0
        self._accel_y = 0.0
        self._accel_z = 0.0
        self._gyro_x  = 0.0
        self._gyro_y  = 0.0
        self._gyro_z  = 0.0

        # Commanded values (saved to allow background loop to resend/keep alive if needed)
        self.cmd_speed = 0
        self.cmd_turn = 0
        self.cmd_jump = 0

    @staticmethod
    def find_port() -> Optional[str]:
        """Scan system serial ports to auto-detect the Arduino or USB-Serial adapter."""
        ports = list(serial.tools.list_ports.comports())
        for p in ports:
            desc = (p.description or '').lower()
            hwid = (p.hwid or '').lower()
            device = p.device
            
            # Common Arduino/CH340/FTDI/CP210X keywords
            keywords = ['arduino', 'uno', 'ch340', 'usb serial', 'ttyacm', 'ttyusb']
            if any(k in desc or k in hwid for k in keywords):
                return device
                
        # Common Raspberry Pi serial fallbacks
        fallbacks = ['/dev/ttyACM0', '/dev/ttyACM1', '/dev/ttyUSB0', '/dev/ttyUSB1']
        for fb in fallbacks:
            if os.path.exists(fb):
                return fb
                
        return None

    def connect(self) -> bool:
        """Start the background driver thread which handles connection and data reading."""
        if self.running:
            return True

        if not self.port:
            detected = self.find_port()
            if detected:
                self.port = detected
            else:
                self.port = "/dev/ttyACM0"  # Default fallback

        self.running = True
        self.thread = threading.Thread(target=self._comm_loop, daemon=True)
        self.thread.start()
        return True

    def disconnect(self) -> None:
        """Clean up background threads and close serial port."""
        self.running = False
        if self.thread is not None:
            self.thread.join(timeout=1.0)
            self.thread = None
            
        with self._write_lock:
            if self.ser is not None:
                try:
                    # Send an emergency stop command before closing
                    self.ser.write(b"CMD:0:0:0\n")
                    self.ser.flush()
                except Exception:
                    pass
                try:
                    self.ser.close()
                except Exception:
                    pass
                self.ser = None
                
        with self._state_lock:
            self._is_connected = False

    def is_connected(self) -> bool:
        """Return True if the serial connection is open and active."""
        with self._state_lock:
            return self._is_connected

    def send_tuning_gains(self, kx: float, kv: float, kp: float, kd: float, ks: float, b_o: float) -> bool:
        """Send LQR tuning gains packet to the Arduino.

        Args:
            kx:  Position-error gain  (N·m/m)
            kv:  Velocity-error gain  (N·m per m/s)
            kp:  Pitch gain           (N·m/rad)
            kd:  Pitch-rate gain      (N·m per rad/s)
            ks:  Torque→PWM scalar    (PWM per N·m)
            b_o: Balance offset       (degrees)
        """
        if not self.is_connected():
            return False

        cmd = f"TUN:{kx:.4f}:{kv:.4f}:{kp:.4f}:{kd:.4f}:{ks:.4f}:{b_o:.4f}\n"
        with self._write_lock:
            if self.ser is None or not self.ser.is_open:
                return False
            try:
                self.ser.write(cmd.encode('utf-8'))
                self.ser.flush()
                return True
            except Exception:
                with self._state_lock:
                    self._is_connected = False
                return False

    def send_servo(self, servo_id: int, pulse_us: int) -> bool:
        """Send a PWM pulse-width command to a BLS3355 hip servo.

        Args:
            servo_id:  1 = left hip (D3), 2 = right hip (D11)
            pulse_us:  Pulse width in microseconds (500–2500).
                       500 = 0°, 1500 = 135° neutral, 2500 = 270°

        Returns True if the command was written successfully.
        """
        pulse_us = max(500, min(2500, int(pulse_us)))
        if not self.is_connected():
            return False
        cmd = f"SRV:{servo_id}:{pulse_us}\n"
        with self._write_lock:
            if self.ser is None or not self.ser.is_open:
                return False
            try:
                self.ser.write(cmd.encode('utf-8'))
                self.ser.flush()
                return True
            except Exception:
                with self._state_lock:
                    self._is_connected = False
                return False

    def send_arm(self) -> bool:
        """Send START command to arm the robot (exits idle/READY state)."""
        if not self.is_connected():
            return False
        with self._write_lock:
            if self.ser is None or not self.ser.is_open:
                return False
            try:
                self.ser.write(b"START\n")
                self.ser.flush()
                return True
            except Exception:
                with self._state_lock:
                    self._is_connected = False
                return False
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

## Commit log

2026-05-16 added code to test jgb520 motors
2026-05-16 modified the feetech motor code to also be compatible with windows
2026-05-17 Added a bill of materials
2026-05-18 updated BOM
2026-05-18 Added script to read the motor position
2026-05-18 attempt to fix torque issue
2026-05-20 fixed temporary id issue with the hip motors. Saved to the wrong address slot 48 vs. now 55
2026-05-20 updated assembly and readme
2026-05-20 refactored project with new format in accordance to the dev branch to stay uniform
    [robot.yaml]
2026-05-20 addressed interupt error in arduino code
    [robot_control.ino]
2026-05-20 added test scripts for imu and wheels as well as lower level code
2026-05-20 added wheels to yaml file
    [robot.yaml]
2026-05-22 added xml files and meshes from other repo
    [chassis.stl, lower_a.stl, lower_b.stl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]
2026-05-22 added lower level arduino - raspberry pi communication bridge
2026-05-22 fixed error in tuning dashboard with viewing imu data
    [tuning_dashboard.py]
2026-05-23 removed feetech control from the arduino code. It was never needed
2026-05-23 add command-line port overrides to motor testing and tuning scripts
2026-05-23 potential fix for motor tests
    [default_stance.py]
2026-05-23 added scsan servos script again for testing
2026-05-23 updated yaml file and other scripts to use the yaml file
    [robot.yaml]
2026-05-24 organized robot.yaml to make a little more sense to me
    [robot.yaml]
2026-05-24 updated yaml and robot ino for arduino
    [robot.yaml]
2026-05-24 added pre-calibration script to find correct pitch angle to tune to
    [calibrate_balance_offset.py, robot_control.py]
2026-05-24 added a timeout to the robot_control arduino code to stop arduino from blocking messages
2026-05-24 fixed sin with the tuning script
    [tuning_dashboard.py]
2026-05-24 fixed typo from ['serial'] to ['hips']
    [default_stance.py]
2026-05-24 added fixed for bluetooth control with
    [bluetooth_controller.py]
2026-05-24 clone Feetech-Servo-SDK repository and integrate into project structure
2026-05-24 fixed error with setTimeout
    [robot_server.py]
2026-05-24 updated serial name for feetech servos
2026-05-24 lqr updaate
    [robot.yaml]
2026-05-25 updated default stance
    [robot.yaml]
2026-06-07 potentially fixed overload error
    [default_stance.py]
2026-06-07 made change to yaml
    [robot.yaml]
2026-06-08 changed made to diagonse problems with the feetech servos
    [robot.yaml]
2026-06-08 updated the BOM
2026-06-08 updated Aseembly with install instructions for the BLS3355 servos
2026-06-08 reparing files for incoming BLS servos
    [robot.yaml]
2026-06-08 removed jumping action and added some safegaurds for the new servos
2026-06-10 Refactor BLS servo configuration and diagnostics
    - Updated robot.yaml to use default_us for stance pulse width.
    - Modified robot_control.ino to synchronize boot stance with config.
    - Renamed diagnostic script to bls_servo_diag.py and added functionality for BLS3355 servos.
    - Created unit tests for stance pulse configuration in test_stance_config.py.
    - Updated default_stance.py and set_hip_angles.py to utilize new stance pulse logic.
    - Enhanced robot_server.py to load and send LQR gains from configuration.
    [robot.yaml]
2026-06-11 updated the assembly file
2026-06-11 Removed dead Feetech serial-bus tooling after BLS3355 migration and Deleted the FeetechBus/FeetechServo driver and its 6 CLI scripts (assign_motor_id, read_feetech_status, test_feetech_motor, set_mot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
    [robot.yaml]
2026-06-11 both motors move to 5 deg and hold
    [robot.yaml]
2026-06-11 added back the mirroring for the wheels
2026-06-11 made adjustments
    [robot.yaml]
2026-06-12 added loop with sin wave to have legs
2026-06-12 reverted changes back to remove the hip leg change. caused error with dst timer being reset which stopped motor pulses
    [display_ip.py]
2026-06-12 updated the new wheel directions for balancing
2026-06-12 updated lqr snapping issue
    [robot_control.ino]
2026-06-12 updated default height
    [robot.yaml]
2026-06-12 update default pose
    [robot.yaml]
